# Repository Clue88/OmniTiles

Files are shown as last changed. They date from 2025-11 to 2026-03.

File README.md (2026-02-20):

# OmniTiles

OmniTiles is a robotics testing platform for ESE Senior Design (2025-26). The main controller is an
STM32F7 that drives the actuators connected to a DWM3001CDK that acts as a wireless bridge (BLE with
Nordic UART Service to STM32 over SPI). A Python GUI can be used for debugging and sending commands.

## Project Layout

**[omnitiles/](omnitiles/)** — Rust firmware for the STM32F7. Handles command parsing, motor
control, and communication over UART and SPI. This is the main firmware.

**[dwm_tag/](dwm_tag/)** — Zephyr app for the nRF52 DWM tag. Receives data over the Nordic UART
Service and passes it to the STM32 over SPI.

**[gui/](gui/)** — Python debug GUI (Viser). Web UI on localhost:8080 to send commands. Connects
over BLE to the DWM tag or optionally over serial.

## System Diagram

```
┌─────────────────┐     BLE (NUS)      ┌──────────────┐    SPI (slave)     ┌─────────────────┐
│  GUI            │ ─────────────────► │  DWM tag     │ ─────────────────► │  OmniTiles      │
│  (Python)       │                    │  (nRF52)     │   DRDY + payload   │  firmware       │
│  localhost:8080 │                    │  OmniTile_1  │                    │  (STM32F7)      │
└─────────────────┘                    └──────────────┘                    └─────────────────┘
        │                                                                          │
        │  UART (e.g. dev board or USB–UART bridge on PCB)                         │
        └──────────────────────────────────────────────────────────────────────────┘
```

Commands from host to STM32 all use the same format: sync byte `0xA5`, message ID, checksum. See
[omnitiles/src/protocol/messages.rs](omnitiles/src/protocol/messages.rs) for the IDs and
[omnitiles/src/protocol/parser.rs](omnitiles/src/protocol/parser.rs) for the parser.

## Quick Start

- **STM32 firmware:** [omnitiles/README.md](omnitiles/README.md) — Rust toolchain, flash, and how to
attach a terminal (`screen` at 115200).
- **DWM tag (nRF52):** [dwm_tag/README.md](dwm_tag/README.md) — building and flashing with the nRF
Connect extension in VS Code.
- **GUI:** [gui/README.md](gui/README.md) — run the Python app, BLE vs UART.

## Documentation

Rust API docs: from the repo root, `cd omnitiles && cargo doc --no-deps --open`. The same docs are
built in CI and published to GitHub Pages on push to `main`. Protocol message definitions and the
parser are in the `omnitiles/src/protocol/` tree.

## License

MIT. See [LICENSE](LICENSE).

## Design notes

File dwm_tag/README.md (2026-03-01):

# DWM tag: BLE-to-SPI bridge

This folder contains the Zephyr firmware for the DWM tag (nRF52) on the OmniTiles. The tag runs as a
BLE peripheral using the Nordic UART Service (NUS). Whatever it receives over BLE it forwards to the
STM32 over SPI, with the nRF52 as SPI slave. The [GUI](../gui/) (or any NUS client) can send command
packets over the air, and the [OmniTiles firmware](../omnitiles/) on the STM32 reads them via SPI.

## Building and flashing (nRF Connect for VS Code)

We use the **nRF Connect for VS Code** extension for building and flashing the DWM tag.

1. Install the [nRF Connect for VS Code](https://marketplace.visualstudio.com/items?itemName=nordic-semiconductor.nrf-connect-for-vscode)
extension if you haven’t already.
2. Open the `dwm_tag` folder in VS Code (or open the repo and have `dwm_tag` as the active folder
for the nRF extension).
3. In the nRF Connect sidebar, add the corresponding build configuration (use `prj.conf` and
`app.overlay` when prompted).
4. Use **Build** to compile the application.
5. Connect the DWM tag and use **Flash** to program it. The extension will use the configured board
and probe.

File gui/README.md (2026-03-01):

# OmniTiles GUI

Python GUI for driving the tile during development. It runs a Viser server (web UI at
http://localhost:8080) with various controls.

The GUI prefers BLE: it scans for the DWM tag and sends command packets over the Nordic UART
Service. If you pass `--port`, it also opens that serial port; when BLE isn’t connected it will send
commands over UART instead. When a serial port is open, the GUI reads lines from UART and prints
them to the console so you can see STM32 debug output.

**Requirements:** Python 3.12+. Dependencies are in [pyproject.toml](pyproject.toml).

**Run:**

```bash
uv sync
uv run python main.py
```

Optional: `--port <device>` to attach a serial port (e.g. `/dev/tty.usbmodem*`), `--baud <rate>`
(default 115200).

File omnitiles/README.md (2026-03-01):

# OmniTiles firmware

Rust firmware for the main MCU (STM32F7). It parses commands from the host over SPI (when the
[DWM tag](../dwm_tag/) is present) or over UART, and drives the actuators and debug output. For how
this fits with the DWM tag and the [GUI](../gui/), see the [root README](../README.md).

See the [generated documentation](https://clue88.github.io/OmniTiles/omnitiles/index.html) for more
details on the Rust firmware for this project.

## Installation

Written for macOS; should work on other Unix-like systems.

Install Rust if needed:

```bash
curl --proto '=https' --tlsv1.2 -sSf https://sh.rustup.rs | sh
```

Then:

```bash
rustup target add thumbv7em-none-eabihf
cargo install probe-rs-tools
```

## Usage

```bash
cargo run --release
```

To watch debug output, attach to the UART at 115200, e.g.:

```bash
screen /dev/tty.usbmodem* 115200
```

Exit screen with `Ctrl+A`, then `Ctrl+\`, then `y`. You can also use `cargo build --release` and
`cargo flash --release` separately. More on the template:
[stm32-template](https://github.com/burrbull/stm32-template/).

### USB–UART bridge (RP2040) on PCB v1

The PCB has an RP2040 (Pico) in front of the MCU UART. To get a debug serial port you need to flash
a USB–UART firmware on the RP2040 once (not needed on a bare dev board). Download the `.uf2` from
[pico-uart-bridge](https://github.com/Noltari/pico-uart-bridge/releases/tag/v4.2), hold BOOT on the
RP2040, plug USB, release BOOT, then drag the `.uf2` onto the `RPI-RP2` volume. After that the debug
terminal works as above.

## Documentation

Message IDs and the frame parser live in `src/protocol/` ([messages.rs](src/protocol/messages.rs),
[parser.rs](src/protocol/parser.rs)).

```bash
cargo doc --no-deps --open
```

CI builds these docs and deploys them to GitHub Pages on push to `main`.

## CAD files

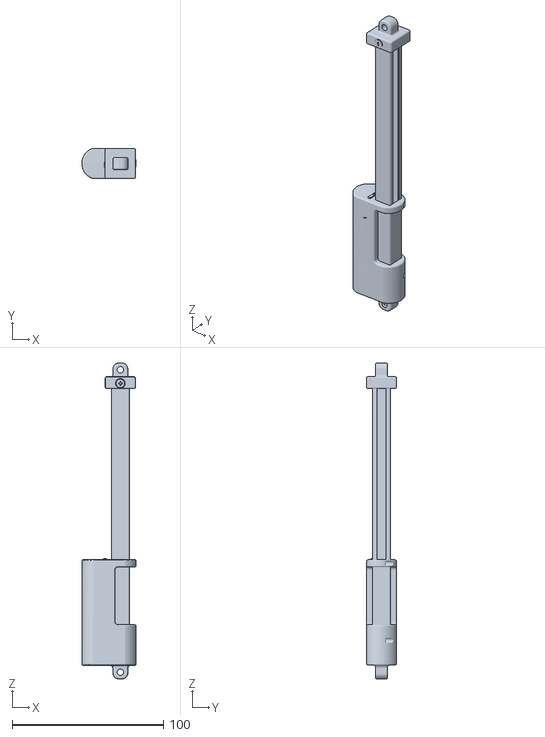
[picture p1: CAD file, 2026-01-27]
gui/t16_base.stl
36.0 x 20.0 x 208.9

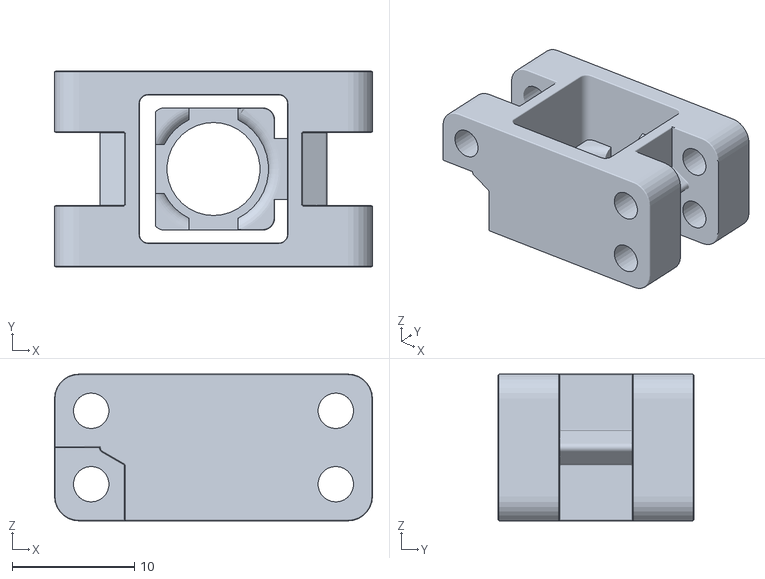
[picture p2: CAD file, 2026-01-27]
gui/t16_carriage.stl
26.0 x 16.0 x 12.0

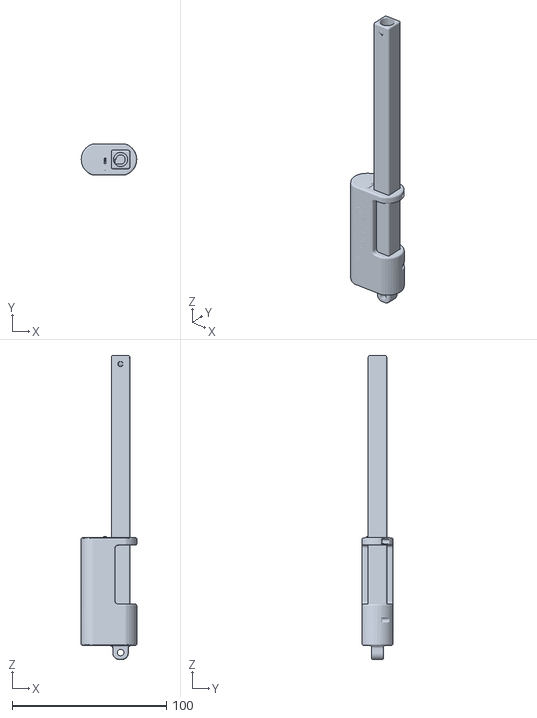
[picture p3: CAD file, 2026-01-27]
gui/p16_base.stl
36.0 x 20.0 x 196.9

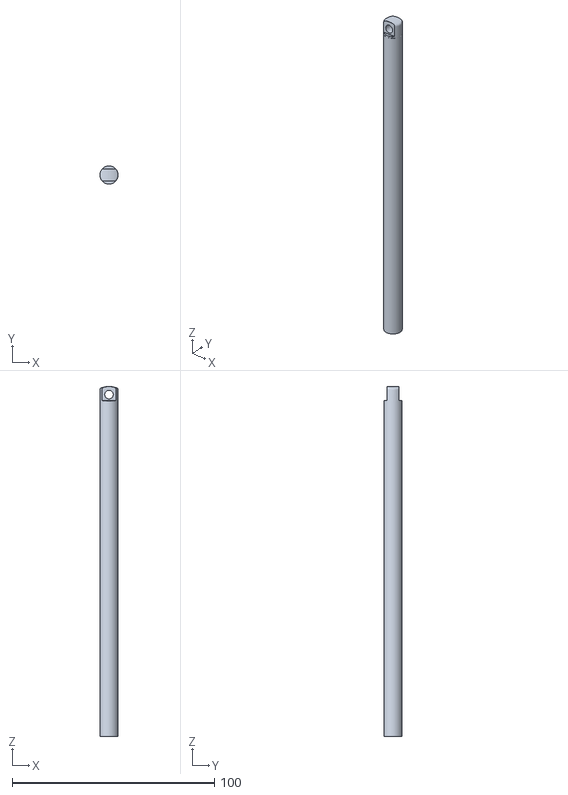
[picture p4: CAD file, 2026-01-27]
gui/p16_shaft.stl
9.00 x 9.00 x 173.0

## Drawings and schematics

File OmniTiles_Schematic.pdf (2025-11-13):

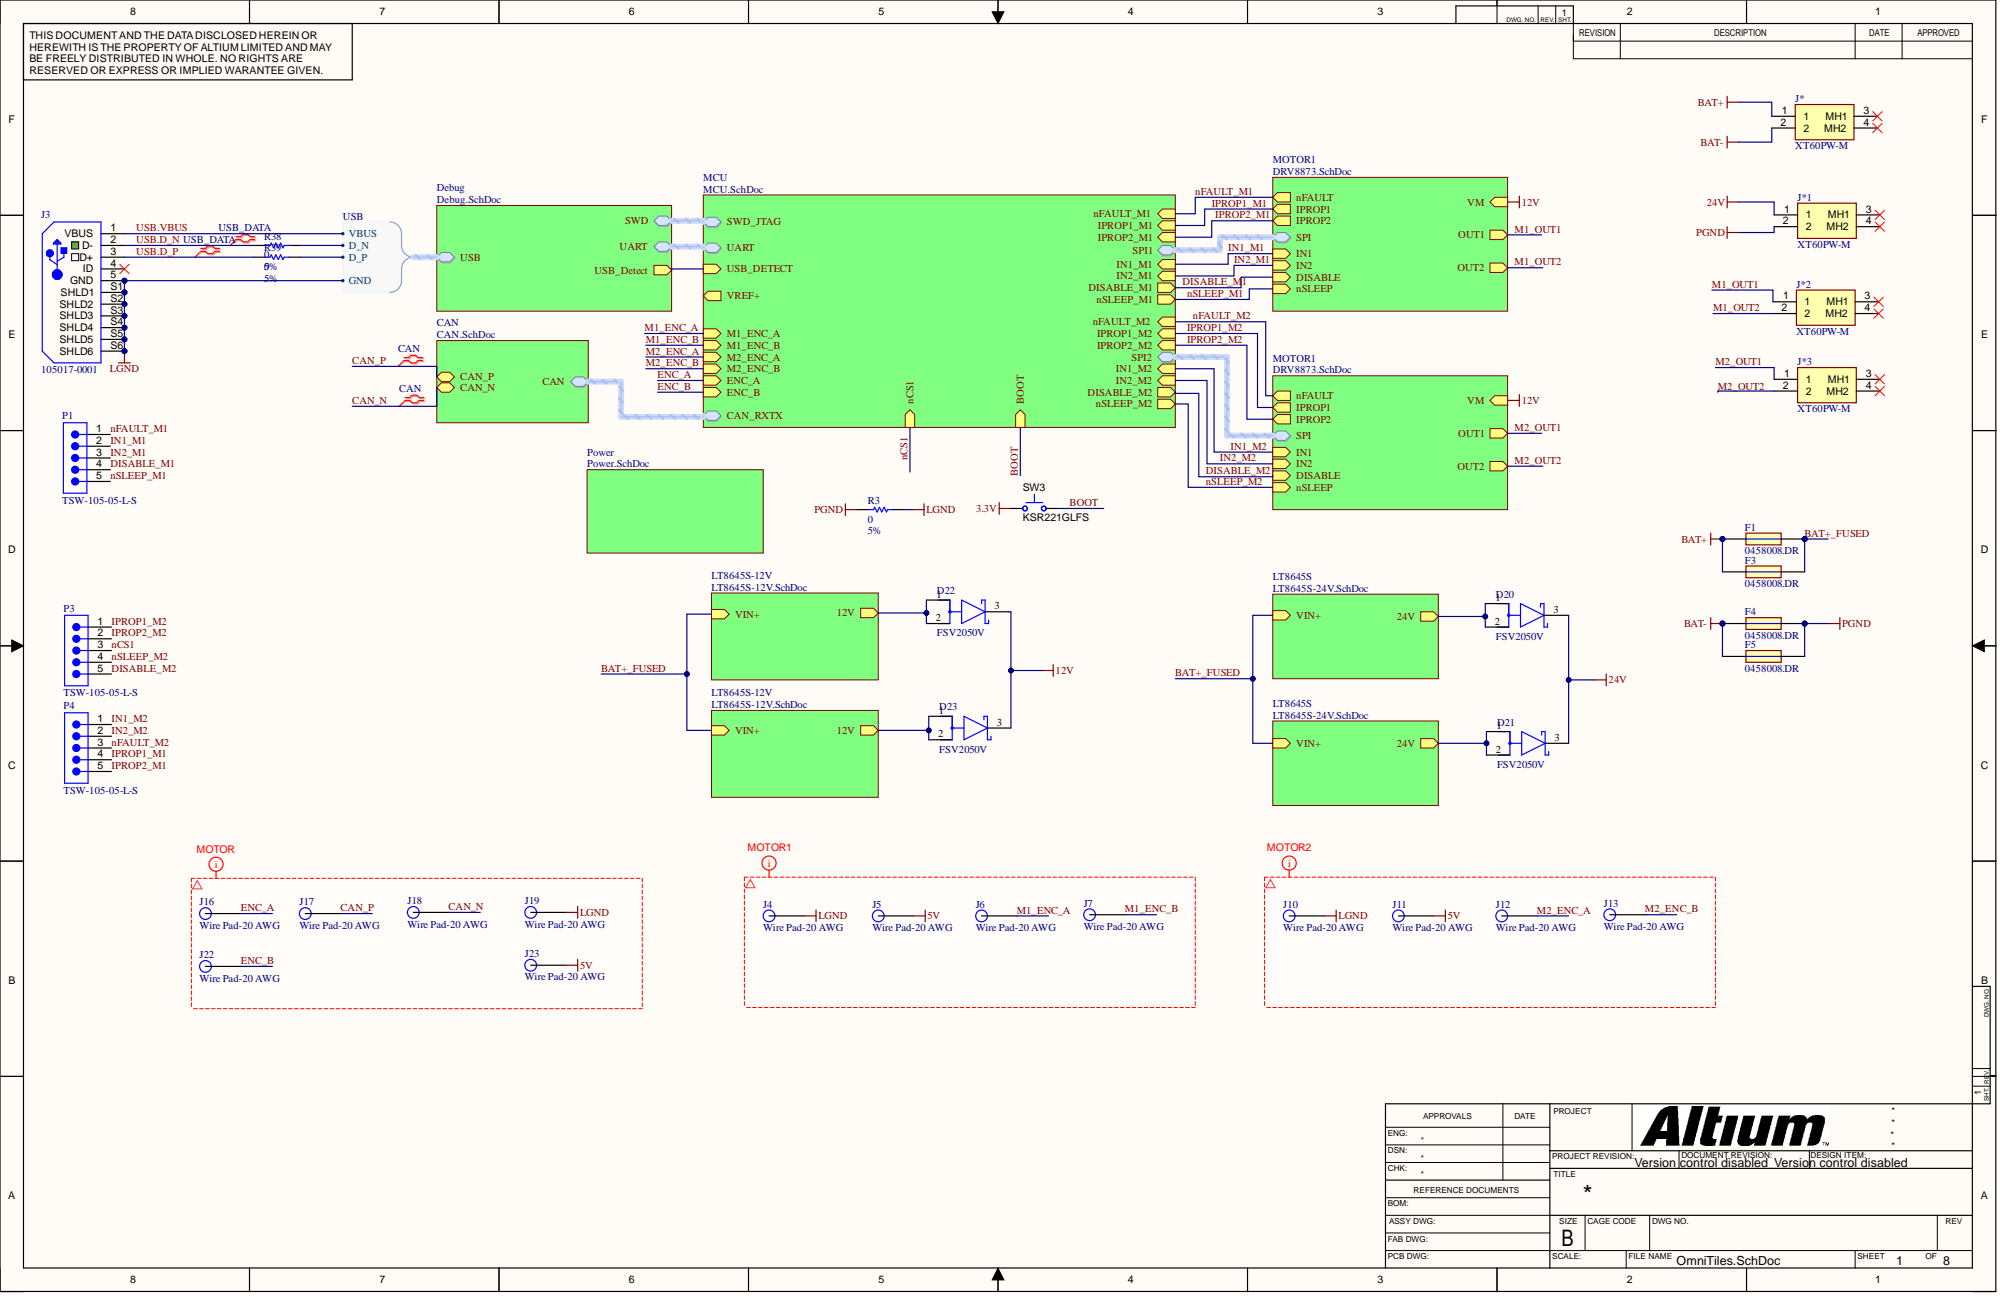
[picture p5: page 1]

DWG. NO. | REV. | SHT.

THIS DOCUMENT AND THE DATA DISCLOSED HEREIN OR HEREWITH IS THE PROPERTY OF ALTIUM LIMITED AND MAY BE FREELY DISTRIBUTED IN WHOLE. NO RIGHTS ARE RESERVED OR EXPRESS OR IMPLIED WARANTEE GIVEN. | MOTOR1 DRV8873.SchDoc | REVISION | DESCRIPTION | DATE | APPROVED

IN2_M2
DISABLE_M2

REV. SHT. DWG. NO.

DATE | PROJECT | * * APPROVALS * *

ENG: *

DSN: *

PROJECT REVISION: Version | DOCUMENT REVISION: control disabled Version control disabled | DESIGN ITEM:

CHK: *

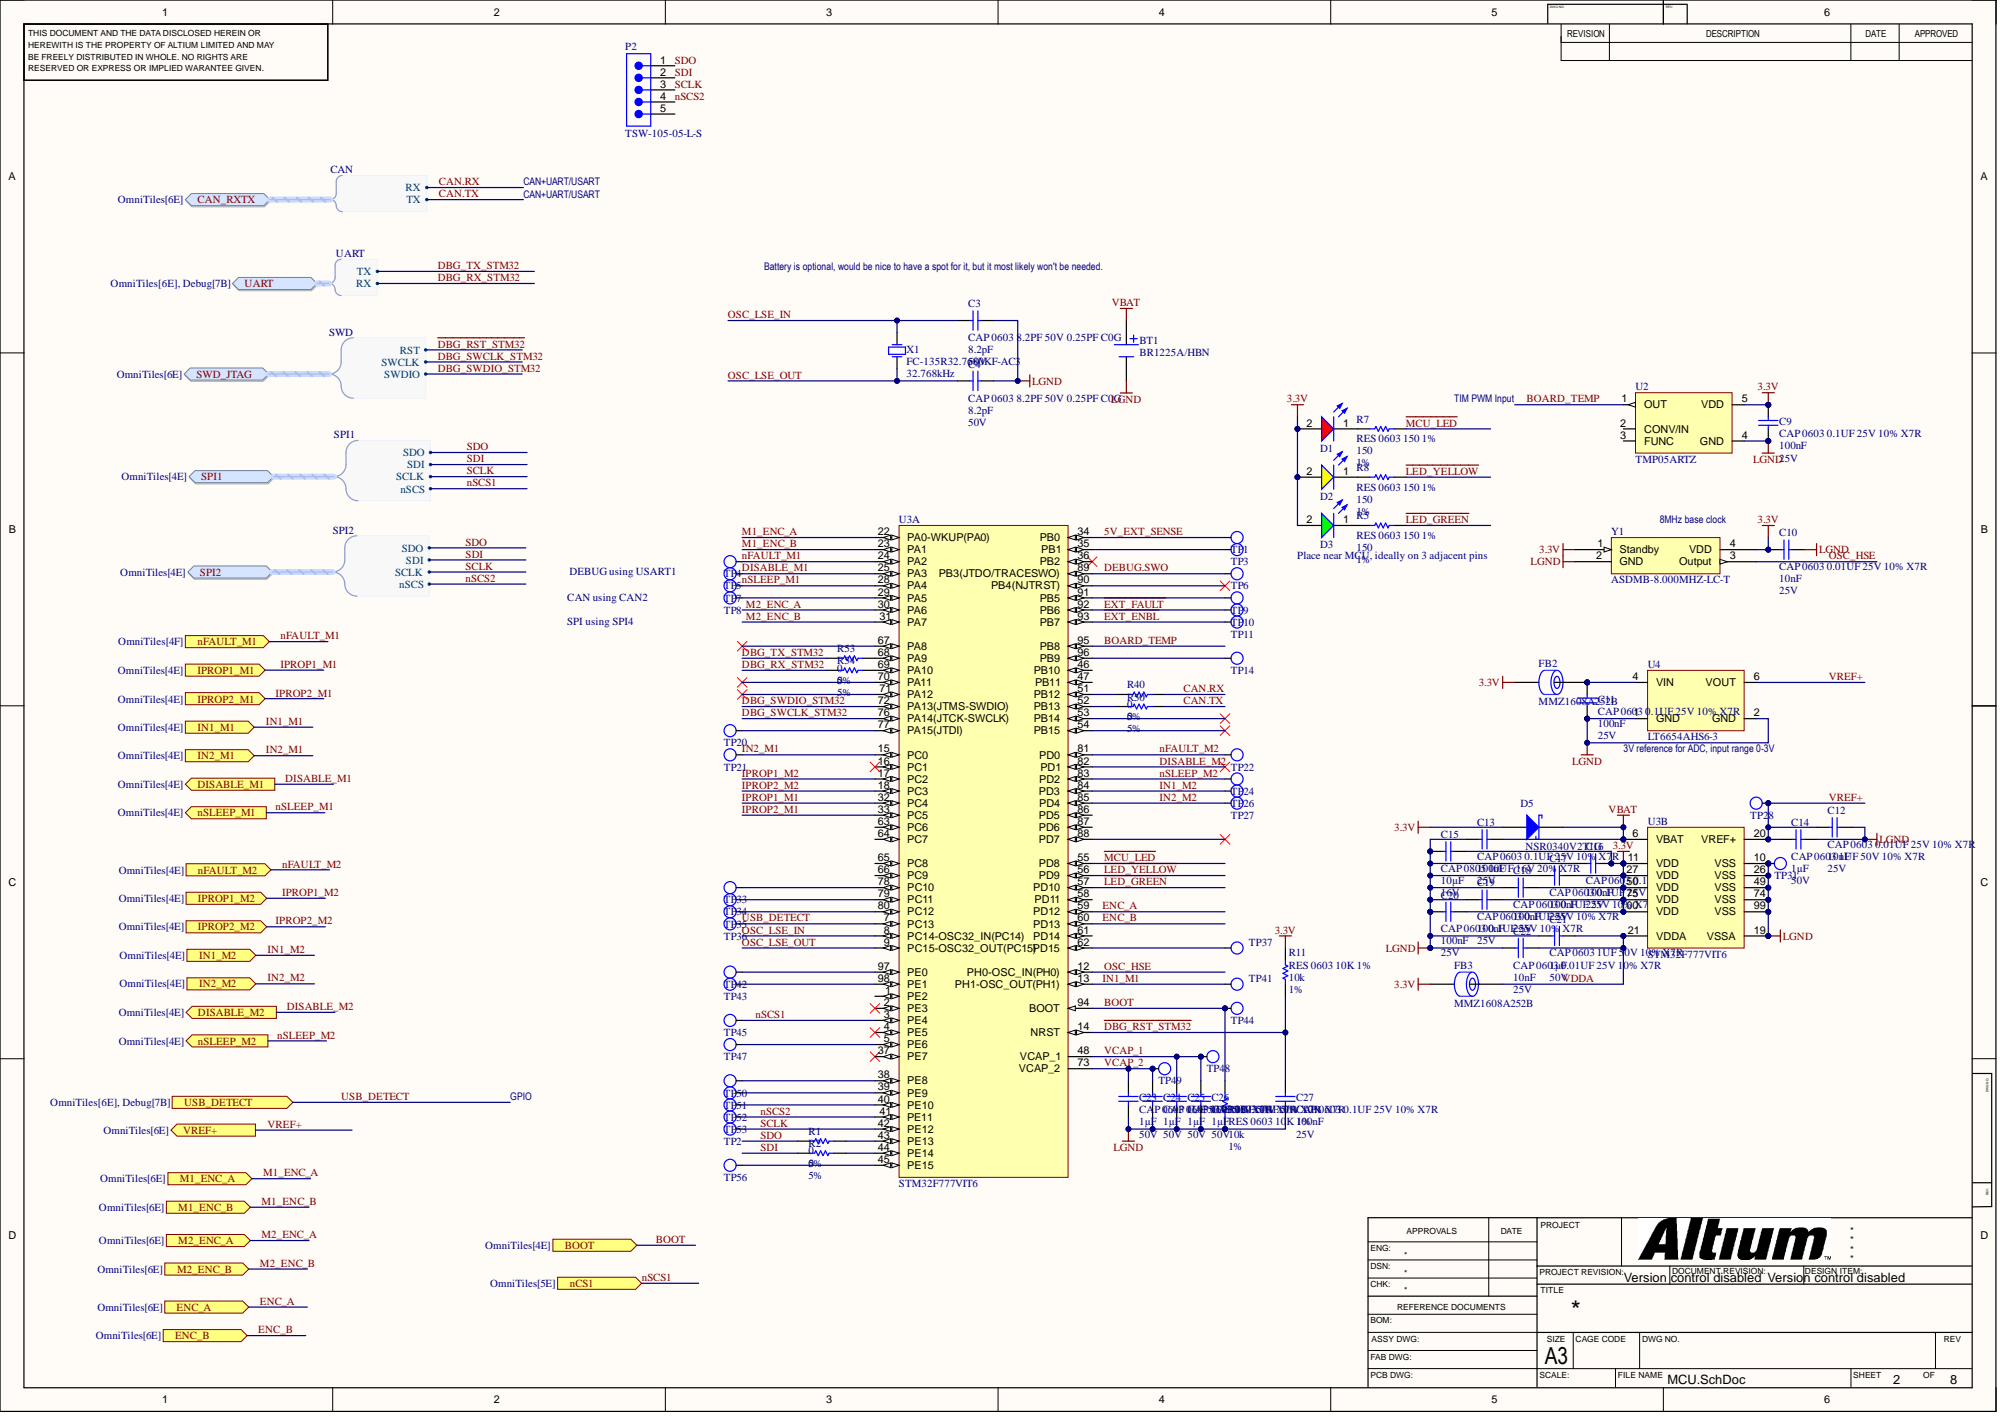
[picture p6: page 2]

DWG NO: | REV:

THIS DOCUMENT AND THE DATA DISCLOSED HEREIN OR HEREWITH IS THE PROPERTY OF ALTIUM LIMITED AND MAY BE FREELY DISTRIBUTED IN WHOLE. NO RIGHTS ARE RESERVED OR EXPRESS OR IMPLIED WARANTEE GIVEN. | P2 | REVISION | DESCRIPTION | DATE | APPROVED

Battery is optional, would be nice to have a spot for it, but it most likely won't be needed.

Place near MCU, ideally on 3 adjacent pins

DBG_RST_STM32

VCAP_1
VCAP_2

DATE | PROJECT | * * APPROVALS * *

ENG: *

DSN: *

CHK: *

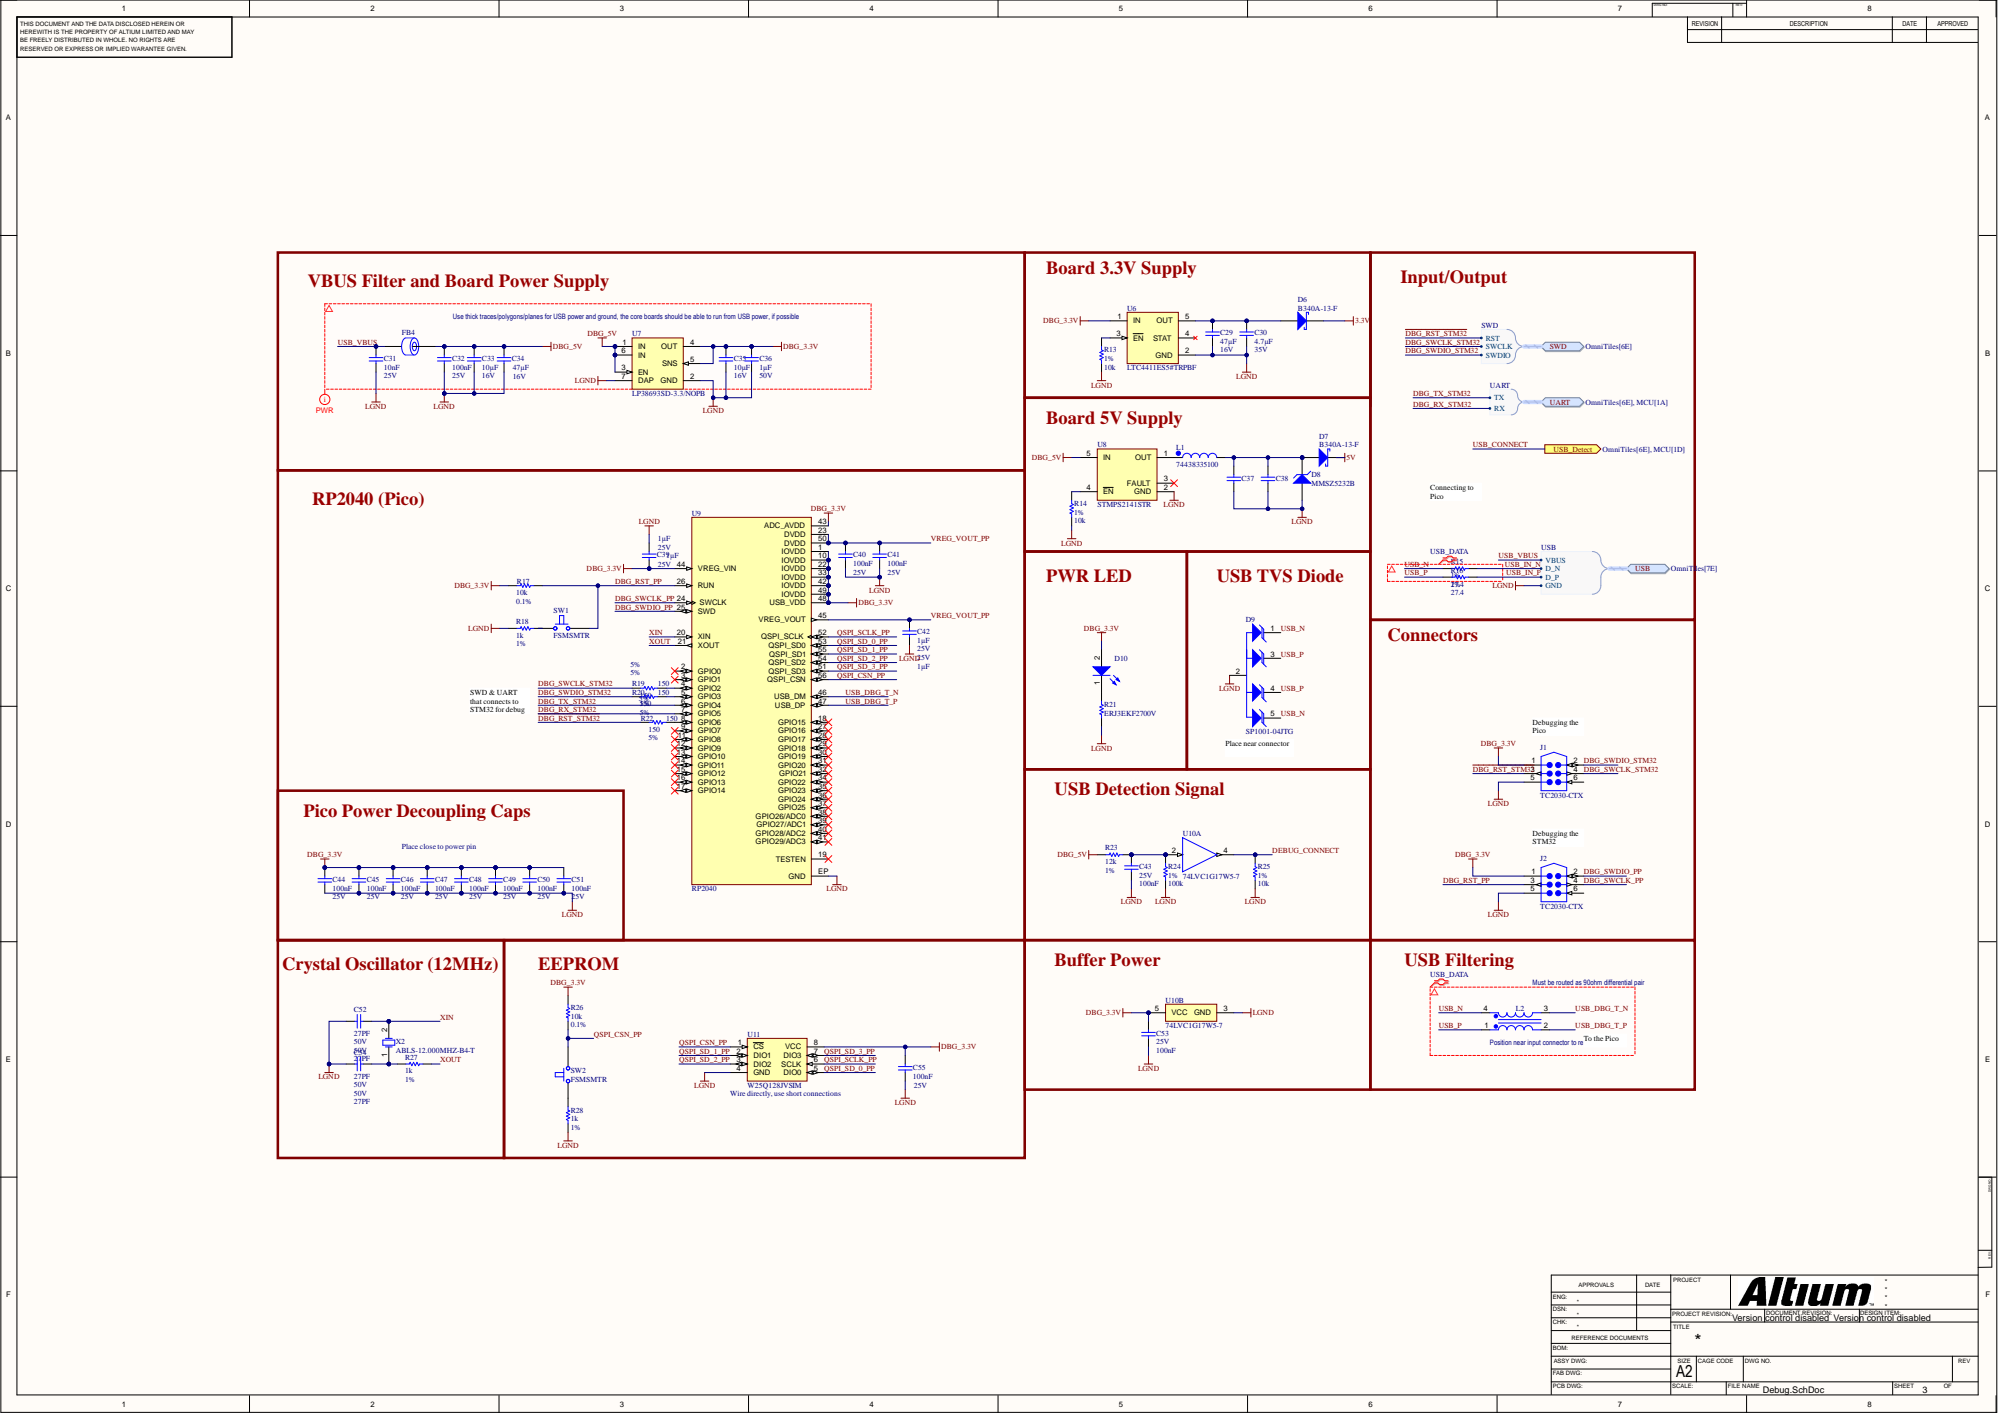
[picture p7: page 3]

DWG NO: | REV:

THIS DOCUMENT AND THE DATA DISCLOSED HEREIN OR HEREWITH IS THE PROPERTY OF ALTIUM LIMITED AND MAY BE FREELY DISTRIBUTED IN WHOLE. NO RIGHTS ARE RESERVED OR EXPRESS OR IMPLIED WARANTEE GIVEN. | | REVISION | DESCRIPTION | DATE | APPROVED

Use thick traces/polygons/planes for USB power and ground, the core boards should be able to run from USB power, if possible

Pico Power Decoupling Caps

Place close to power pin

Must be routed as 90ohm differential pair

Position near input connector to remove HF noise

W25Q128JVSIM
Wire directly, use short connections

DATE | PROJECT | * * APPROVALS * *

ENG: *

DSN: *

PROJECT REVISION: Version | DOCUMENT REVISION: control disabled Version control disabled | DESIGN ITEM:

CHK: *

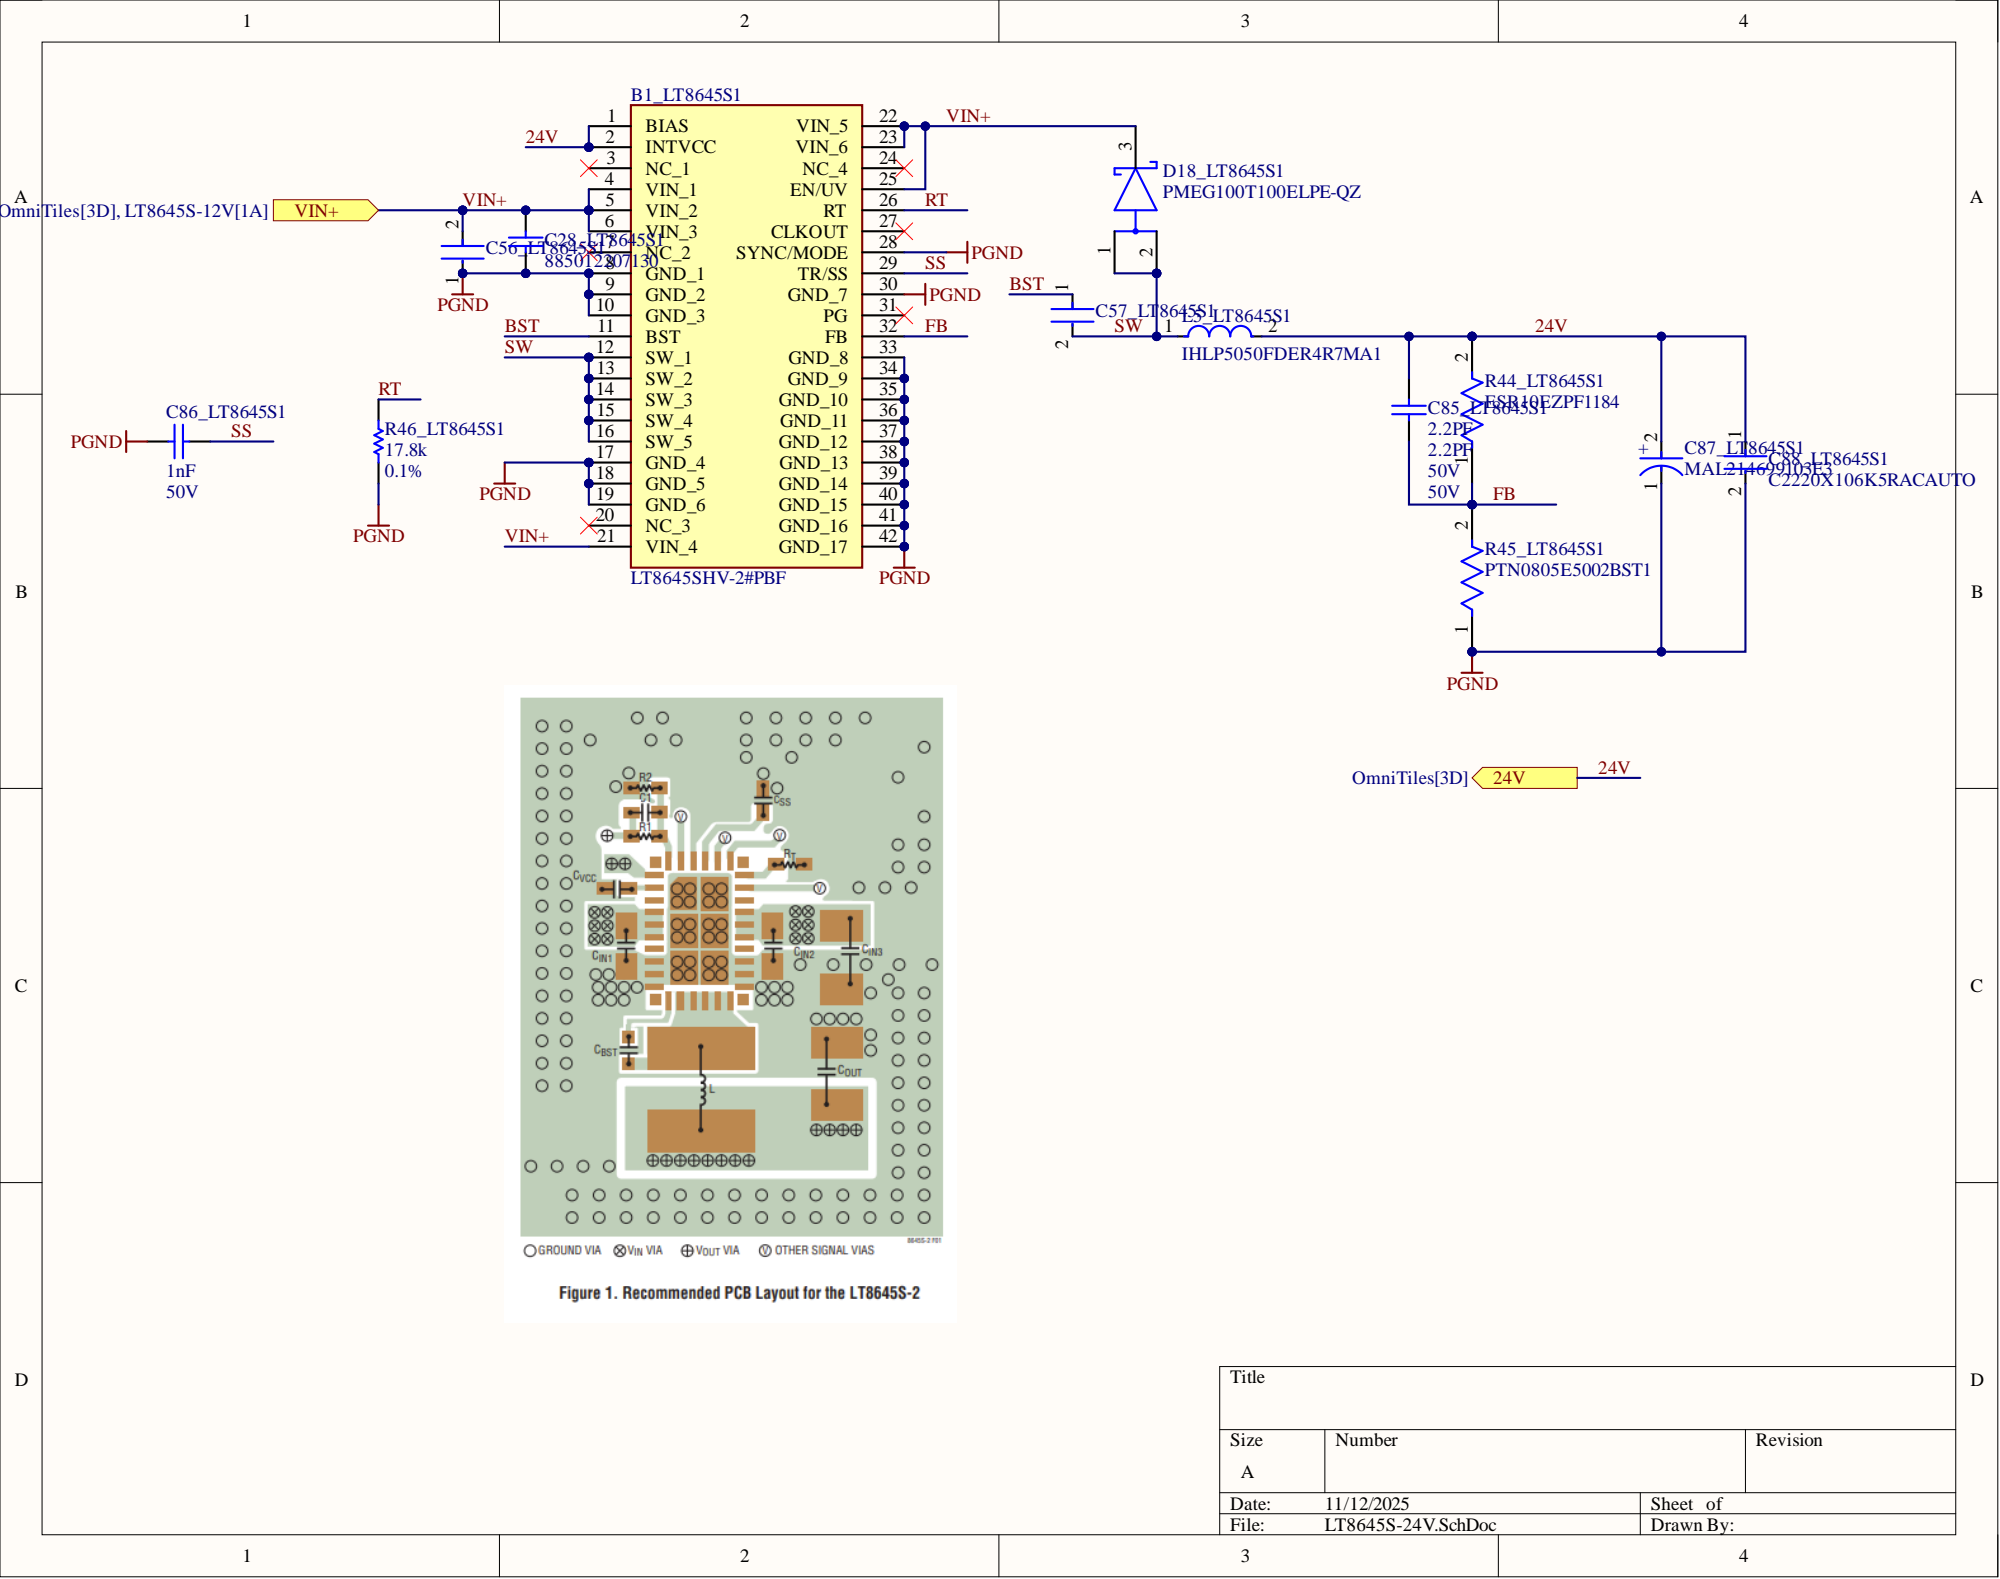
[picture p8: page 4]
PIC280LT8645S102 COC28; PIC560LT8645S102 COC56; PIC570LT8645S102 COC57; PIC850LT8645S102 COC85; PIC870LT8645S102 COC87; PIC880LT8645S101; PIC880LT8645S102 COC88; PID180LT8645S101 PID180LT8645S102; PID180LT8645S103 COD18; PIR440LT8645S102 COR44; PIR450LT8645S102 COR45; PIR460LT8645S102 COR46; PIR460LT8645S102 NLRT; NLVIN0 POVIN0; PIC280LT8645S202 COC28; PIC560LT8645S202 COC56; PIC570LT8645S202 COC57; PIC850LT8645S202 COC85; PIC870LT8645S202 COC87; PIC880LT8645S201; PIC880LT8645S202 COC88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

2 PIB10LT8645S102 PIB10LT8645S102 PIB10LT8645S202 PIB10LT8645S202 | 2 3 PIB10LT8645S1023 PIB10LT8645S1023 PIB10LT8645S2023 PIB10LT8645S2023

2 4 PIB10LT8645S1024 PIB10LT8645S1024 PIB10LT8645S2024 PIB10LT8645S2024

N D | 9 PIB10LT8645S109 PIB10LT8645S109 PIB10LT8645S209 PIB10LT8645S209

1 0 PIB10LT8645S1010 PIB10LT8645S1010 PIB10LT8645S2010 PIB10LT8645S2010 | | PIB10LT8645S1031 PIB10LT8645S1031 PIB10LT8645S2031 PIB10LT8645S2031

1 5 PIB10LT8645S1015 PIB10LT8645S1015 PIB10LT8645S2015 PIB10LT8645S2015 | 3 6
1 6 PIB10LT8645S1016 PIB10LT8645S1016 PIB10LT8645S2016 PIB10LT8645S2016 | 3 7 PIB10LT8645S1037 PIB10LT8645S1037 PIB10LT8645S2037 PIB10LT8645S2037

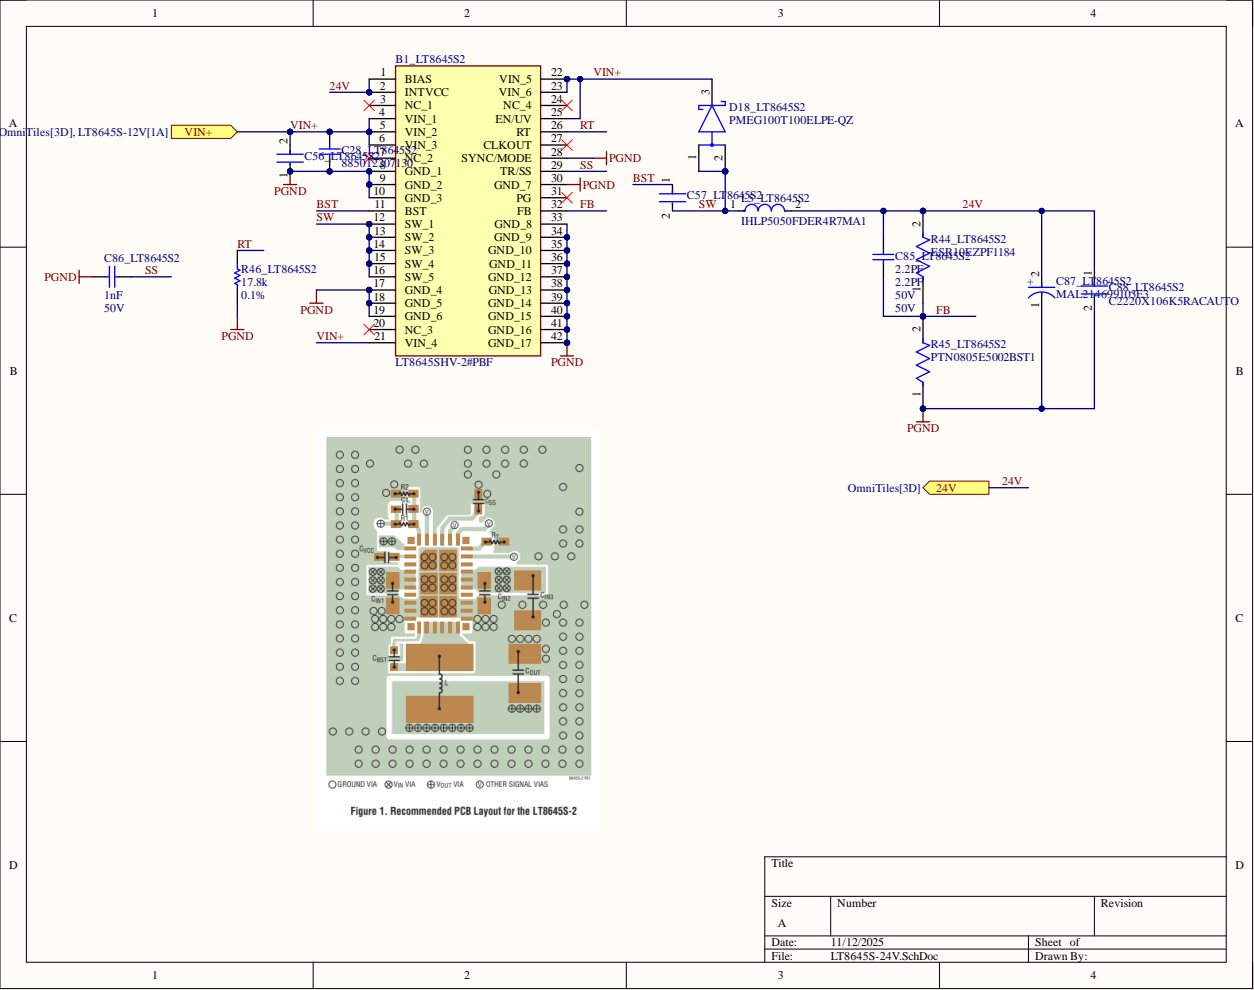
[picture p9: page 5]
Date:; Sheet of; File:; LT8645S-24V.SchDoc; Drawn By:; BIAS 1 INTVCC 2 NC_1 3 VIN_1 4 VIN_2 5 VIN_3 6 NC_2 7 GND_1 8 GND_2 9 GND_3 10 BST 11 SW_1 12 SW_2 13 SW_3 14 SW_4 15 SW_5 16 GND_4 17 GND_5 18 GND_6 19 NC_3 20 VIN_4 21; 2 D18_LT8645S2 PMEG100T100ELPE-QZ VIN+; OmniTiles[3D], LT8645S-12V[1A]; VIN+

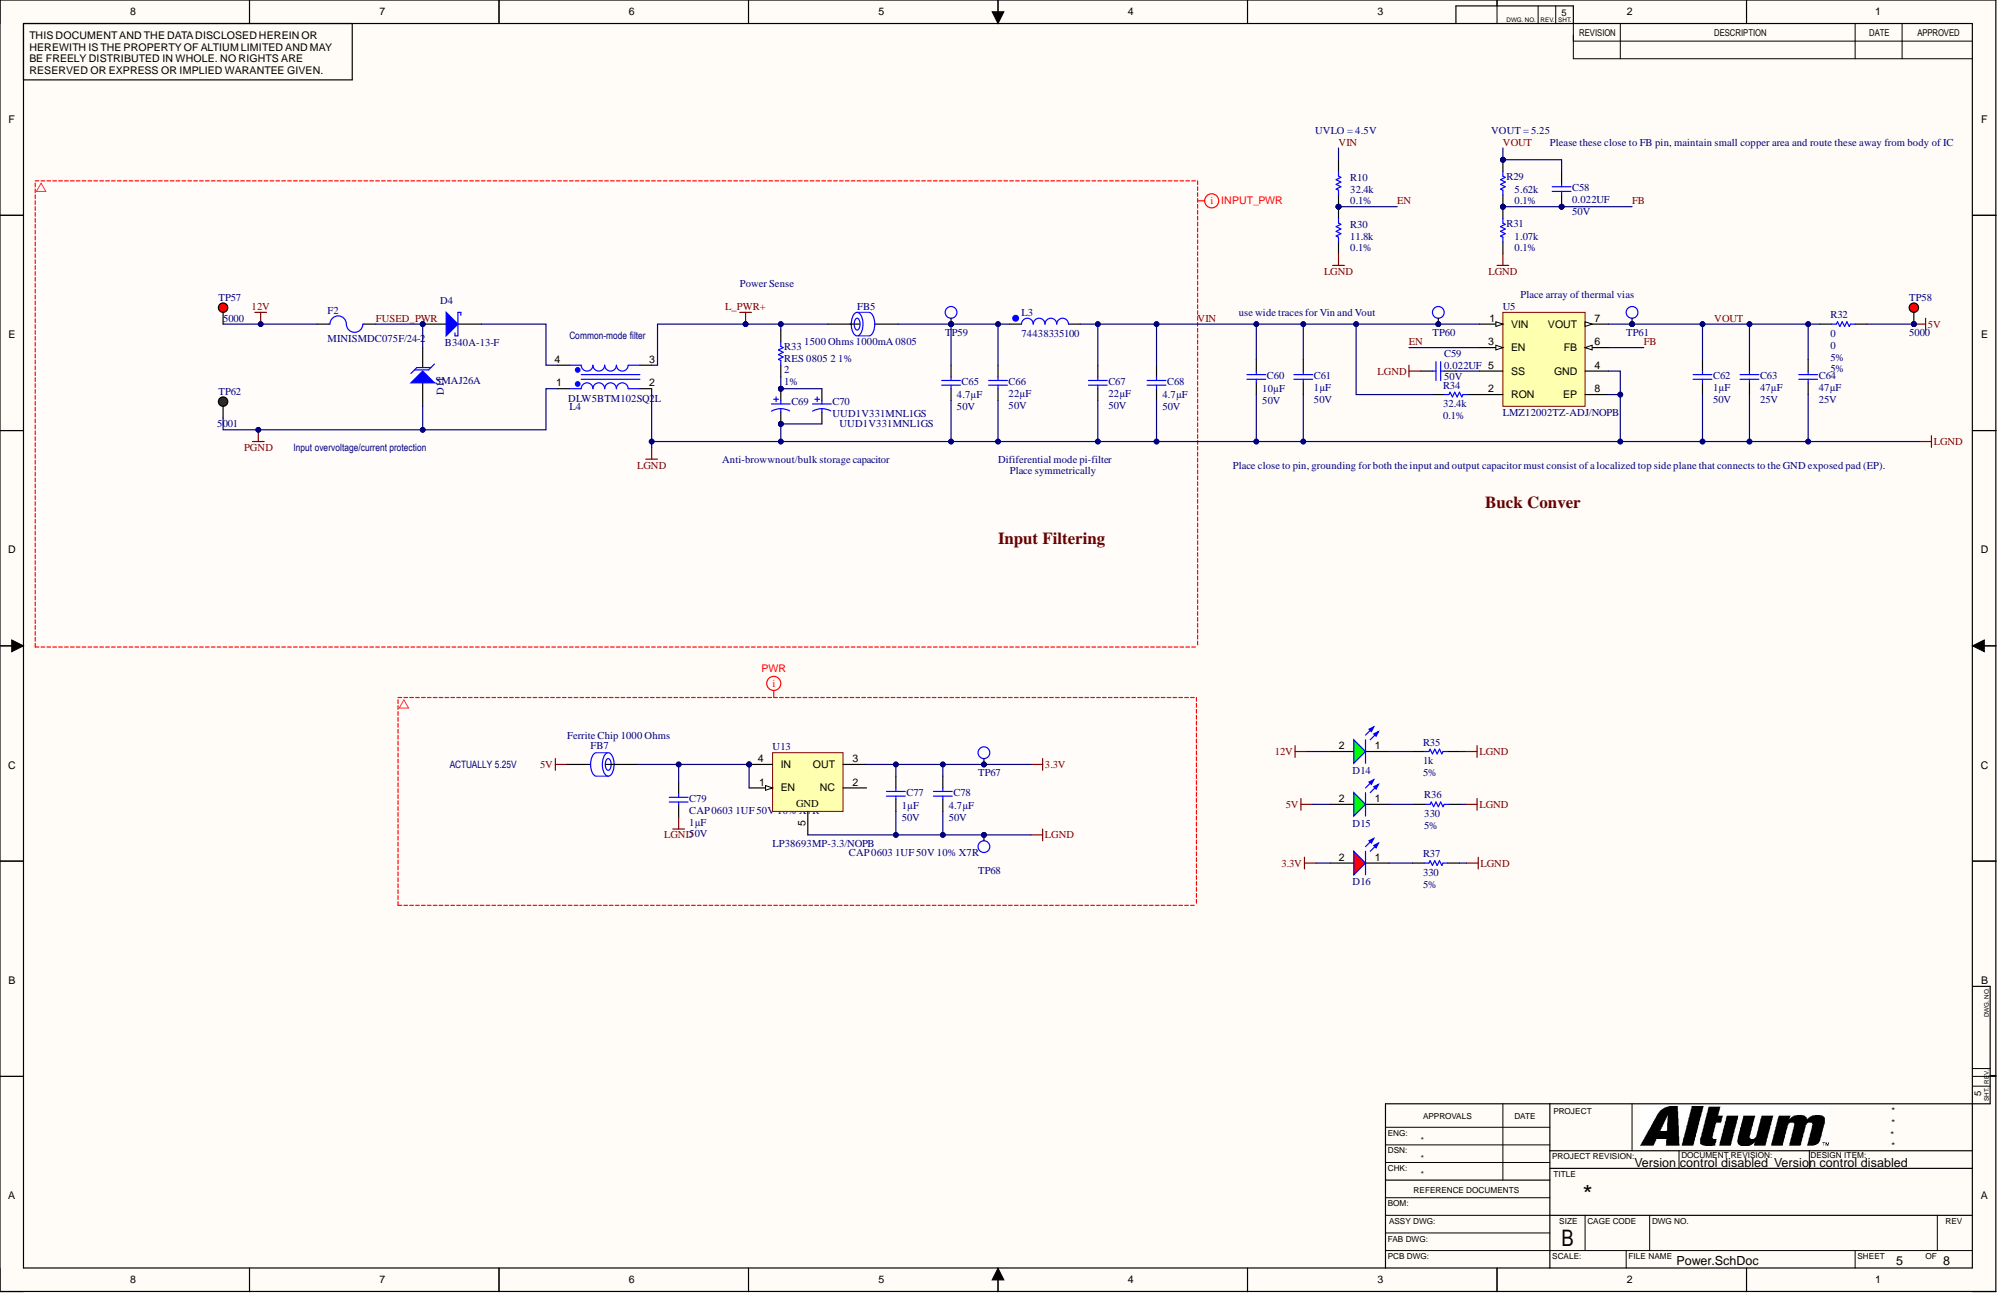
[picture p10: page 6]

DWG. NO. | REV. | SHT.

THIS DOCUMENT AND THE DATA DISCLOSED HEREIN OR HEREWITH IS THE PROPERTY OF ALTIUM LIMITED AND MAY BE FREELY DISTRIBUTED IN WHOLE. NO RIGHTS ARE RESERVED OR EXPRESS OR IMPLIED WARANTEE GIVEN. | UVLO = 4.5V VOUT = 5.25 VIN VOUT | REVISION | DESCRIPTION | DATE | APPROVED

Please these close to FB pin, maintain small copper area and route these away from body of IC

Place array of thermal vias
5V TP61 VIN 1

use wide tracesfor Vin and Vout 12V

Input overvoltage/current protection

Anti-browwnout/bulk storage capacitor

Dififerential mode pi-filter
Place symmetrically

Place close to pin, grounding for both the input and output capacitor must consist of a localized top side plane that connects to the GND exposed pad (EP).

REV. SHT. DWG. NO.

DATE | PROJECT | * * APPROVALS * *

ENG: *

DSN: *

PROJECT REVISION: Version | DOCUMENT REVISION: control disabled Version control disabled | DESIGN ITEM:

CHK: *
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

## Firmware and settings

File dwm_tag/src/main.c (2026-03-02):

// SPDX-License-Identifier: MIT
// © 2025–2026 Christopher Liu

/*
 * DWM tag (nRF52) application: BLE-to-SPI bridge.
 *
 * Runs as a BLE peripheral (Nordic UART Service), advertising as OmniTile_1.
 * Data received from a device is queued and then sent to the STM32 over SPI when
 * the master asserts CS. A DRDY GPIO is driven high when a payload is ready and
 * cleared after the SPI transaction completes.
 */

#include <bluetooth/services/nus.h>
#include <zephyr/bluetooth/bluetooth.h>
#include <zephyr/bluetooth/conn.h>
#include <zephyr/bluetooth/gatt.h>
#include <zephyr/bluetooth/uuid.h>
#include <zephyr/drivers/gpio.h>
#include <zephyr/drivers/spi.h>
#include <zephyr/kernel.h>
#include <zephyr/logging/log.h>
#include <zephyr/net/ieee802154_mgmt.h>
#include <zephyr/net/net_if.h>
#include <zephyr/net/net_ip.h>
#include <zephyr/net/net_mgmt.h>
#include <zephyr/net/socket.h>

LOG_MODULE_REGISTER(main);

#define UWB_THREAD_STACK_SIZE 2048
#define UWB_THREAD_PRIORITY   10
#define UWB_POLL_INTERVAL_MS  100
#define UWB_ANCHOR_PORT       4242
#define UWB_POLL_PAYLOAD      "Poll"
#define UWB_POLL_LEN          4

#define SPI_SLAVE_NODE DT_NODELABEL(my_spis)
#define DRDY_GPIO_NODE DT_ALIAS(spis_drdy_gpios)
#define SPI_BUF_SIZE   128

/* Protocol: same as STM32/omnitiles (START_BYTE, msg_id, checksum). No payload => checksum = msg_id */
#define CMD_START_BYTE 0xA5
#define CMD_M1_BRAKE   0x32
#define CMD_M2_BRAKE   0x42

/* Define NUS UUID so scanners can see us in Scan Response */
#define NUS_UUID_Service_Val                                                             \
  0x9E, 0xCA, 0xDC, 0x24, 0x0E, 0xE5, 0xA9, 0xE0, 0x93, 0xF3, 0xA3, 0xB5, 0x01, 0x00,    \
      0x40, 0x6E

/* Shared state: distances to three UWB anchors in mm (volatile ok for mock) */
static volatile uint16_t uwb_distances_mm[3] = {0, 0, 0};

static const struct bt_data ad[] = {
    BT_DATA_BYTES(BT_DATA_FLAGS, (BT_LE_AD_GENERAL | BT_LE_AD_NO_BREDR)),
    BT_DATA(BT_DATA_NAME_COMPLETE, "OmniTile_1", 10),
};

static const struct bt_data sd[] = {
    BT_DATA_BYTES(BT_DATA_UUID128_ALL, NUS_UUID_Service_Val),
};

static struct k_work adv_work;
static struct bt_conn* current_conn;

/* Avoid flooding BLE and stressing stack: rate-limit NUS send and back off on failure */
#define NUS_SEND_INTERVAL_MS 50
#define NUS_SEND_BACKOFF_MS  3000
static uint32_t last_nus_send_ms;
static uint32_t nus_send_backoff_until_ms;

/* Set in disconnected(); main loop sends M1+M2 brake to STM32 on next SPI transaction */
static volatile bool send_brake_on_disconnect;
/* Set in bt_receive_cb when queue is full; main loop sends M1+M2 brake on next SPI transaction */
static volatile bool send_brake_on_queue_full;

static void adv_work_handler(struct k_work* work) {
  int err =
      bt_le_adv_start(BT_LE_ADV_CONN_FAST_1, ad, ARRAY_SIZE(ad), sd, ARRAY_SIZE(sd));
  if (err) {
    LOG_ERR("Advertising failed to restart (err %d)", err);
  }
}

static const struct device* const spi_dev = DEVICE_DT_GET(SPI_SLAVE_NODE);
static const struct gpio_dt_spec drdy_pin = GPIO_DT_SPEC_GET(DRDY_GPIO_NODE, gpios);

K_MSGQ_DEFINE(ble_msgq, SPI_BUF_SIZE, 32, 4);

static uint8_t tx_buffer[SPI_BUF_SIZE];
static uint8_t rx_buffer[SPI_BUF_SIZE];

static const struct spi_config spi_cfg = {
    .operation = SPI_WORD_SET(8) | SPI_TRANSFER_MSB | SPI_OP_MODE_SLAVE,
};

static void set_drdy(bool active) {
  gpio_pin_set_dt(&drdy_pin, active ? 1 : 0);
}

/* BLE callbacks */

static void bt_receive_cb(struct bt_conn* conn, const uint8_t* const data, uint16_t len) {
  uint8_t temp_buf[SPI_BUF_SIZE];

  uint16_t copy_len = (len > SPI_BUF_SIZE) ? SPI_BUF_SIZE : len;
  memcpy(temp_buf, data, copy_len);

  if (copy_len < SPI_BUF_SIZE) {
    memset(temp_buf + copy_len, 0, SPI_BUF_SIZE - copy_len);
  }

  if (k_msgq_put(&ble_msgq, temp_buf, K_NO_WAIT) != 0) {
    LOG_WRN("BLE Queue Full");
    send_brake_on_queue_full = true;
  }
}

static struct bt_nus_cb nus_cb = {
    .received = bt_receive_cb,
};

static void connected(struct bt_conn* conn, uint8_t err) {
  if (err) {
    LOG_ERR("Connection failed (err 0x%02x)", err);
    return;
  }

  LOG_INF("Connected");

  /* Track the current connection for NUS TX */
  current_conn = bt_conn_ref(conn);
}

static void disconnected(struct bt_conn* conn, uint8_t reason) {
  LOG_INF("Disconnected (reason 0x%02x). Restarting advertising...", reason);

  if (current_conn == conn) {
    send_brake_on_disconnect = true;
    bt_conn_unref(current_conn);
    current_conn = NULL;
    nus_send_backoff_until_ms = 0;
  }

  k_work_submit(&adv_work);
}

BT_CONN_CB_DEFINE(conn_callbacks) = {
    .connected = connected,
    .disconnected = disconnected,
};

static void bt_ready(int err) {
  if (err) {
    LOG_ERR("BLE init failed (err %d)", err);
    return;
  }
  LOG_INF("BLE Initialized");

  err = bt_nus_init(&nus_cb);
  if (err) {
    LOG_ERR("Failed to init NUS (err %d)", err);
    return;
  }

  err = bt_le_adv_start(BT_LE_ADV_CONN_FAST_1, ad, ARRAY_SIZE(ad), sd, ARRAY_SIZE(sd));
  if (err) {
    LOG_ERR("Advertising failed (err %d)", err);
  } else {
    LOG_INF("Advertising started as OmniTile_1");
  }
}

static struct net_if* uwb_iface_found;

static void find_ieee802154_cb(struct net_if* iface, void* user_data) {
  uint16_t ch;
  if (uwb_iface_found != NULL) {
    return;
  }
  if (net_mgmt(NET_REQUEST_IEEE802154_GET_CHANNEL, iface, &ch, sizeof(ch)) == 0) {
    uwb_iface_found = iface;
  }
}

static void uwb_thread_entry(void* p1, void* p2, void* p3) {
  ARG_UNUSED(p1);
  ARG_UNUSED(p2);
  ARG_UNUSED(p3);

  struct sockaddr_in6 dst;
  int fd;
  int ret;

  uwb_iface_found = NULL;
  net_if_foreach(find_ieee802154_cb, NULL);
  if (uwb_iface_found == NULL || !net_if_is_up(uwb_iface_found)) {
    LOG_ERR("UWB: no IEEE 802.15.4 interface or not up");
    k_thread_suspend(k_current_get());
    return;
  }

  fd = zsock_socket(AF_INET6, SOCK_DGRAM, IPPROTO_UDP);
  if (fd < 0) {
    LOG_ERR("UWB: socket create failed (%d)", fd);
    k_thread_suspend(k_current_get());
    return;
  }

  memset(&dst, 0, sizeof(dst));
  dst.sin6_family = AF_INET6;
  dst.sin6_port = htons(UWB_ANCHOR_PORT);
  /* ff02::1 (all-nodes multicast) */
  dst.sin6_addr.s6_addr[0] = 0xff;
  dst.sin6_addr.s6_addr[1] = 0x02;
  dst.sin6_addr.s6_addr[15] = 0x01;

  for (;;) {
    ret = zsock_sendto(
        fd, UWB_POLL_PAYLOAD, UWB_POLL_LEN, 0, (struct sockaddr*)&dst, sizeof(dst));
    if (ret < 0) {
      LOG_WRN("UWB: sendto failed (%d)", ret);
    }

    /* Mock: update distances (base + small increment to simulate movement) */
    static uint16_t tick;
    tick++;
    uwb_distances_mm[0] = 1000 + (tick % 200);
    uwb_distances_mm[1] = 2000 + (tick % 200);
    uwb_distances_mm[2] = 3000 + (tick % 200);

    k_msleep(UWB_POLL_INTERVAL_MS);
  }
}

K_THREAD_DEFINE(uwb_thread,
    UWB_THREAD_STACK_SIZE,
    uwb_thread_entry,
    NULL,
    NULL,
    NULL,
    UWB_THREAD_PRIORITY,
    0,
    0);

int main(void) {
  int ret;

  if (!gpio_is_ready_dt(&drdy_pin) || !device_is_ready(spi_dev)) {
    LOG_ERR("Hardware init failed");
    return -1;
  }
  gpio_pin_configure_dt(&drdy_pin, GPIO_OUTPUT_INACTIVE);

  k_work_init(&adv_work, adv_work_handler);

  ret = bt_enable(bt_ready);
  if (ret) {
    LOG_ERR("Bluetooth enable failed");
    return -1;
  }

  LOG_INF("System Ready. Waiting for BLE data...");

  while (1) {
    ret = k_msgq_get(&ble_msgq, tx_buffer, K_MSEC(1000));

    if (ret != 0) {
      memset(tx_buffer, 0, SPI_BUF_SIZE);
    }

    /* On BLE disconnect, send brake to STM32 so motors stop when link is lost */
    if (send_brake_on_disconnect) {
      send_brake_on_disconnect = false;
      tx_buffer[0] = CMD_START_BYTE;
      tx_buffer[1] = CMD_M1_BRAKE;
      tx_buffer[2] = CMD_M1_BRAKE;
      tx_buffer[3] = CMD_START_BYTE;
      tx_buffer[4] = CMD_M2_BRAKE;
      tx_buffer[5] = CMD_M2_BRAKE;
      memset(tx_buffer + 6, 0, SPI_BUF_SIZE - 6);
    }
    /* When queue overflowed, send brake so actuators stop immediately */
    if (send_brake_on_queue_full) {
      send_brake_on_queue_full = false;
      tx_buffer[0] = CMD_START_BYTE;
      tx_buffer[1] = CMD_M1_BRAKE;
      tx_buffer[2] = CMD_M1_BRAKE;
      tx_buffer[3] = CMD_START_BYTE;
      tx_buffer[4] = CMD_M2_BRAKE;
      tx_buffer[5] = CMD_M2_BRAKE;
      memset(tx_buffer + 6, 0, SPI_BUF_SIZE - 6);
    }

    struct spi_buf tx_buf = {.buf = tx_buffer, .len = SPI_BUF_SIZE};
    struct spi_buf_set tx = {.buffers = &tx_buf, .count = 1};

    struct spi_buf rx_buf = {.buf = rx_buffer, .len = SPI_BUF_SIZE};
    struct spi_buf_set rx = {.buffers = &rx_buf, .count = 1};

    set_drdy(true);
    ret = spi_transceive(spi_dev, &spi_cfg, &tx, &rx);
    set_drdy(false);

    // Check for incoming telemetry packet and forward over BLE
    if (rx_buffer[0] == 0xA5 && rx_buffer[1] == 0x60) {
      uint8_t checksum = (rx_buffer[1] + rx_buffer[2] + rx_buffer[3]) & 0xFF;
      if (rx_buffer[4] != checksum) {
        LOG_WRN(
            "Telemetry checksum mismatch (got %02X, expected %02X) — forwarding anyway",
            rx_buffer[4],
            checksum);
      }

      if (current_conn == NULL) {
      } else {
        uint32_t now = k_uptime_get_32();
        bool in_backoff = (now < nus_send_backoff_until_ms);
        bool rate_ok = (now - last_nus_send_ms >= NUS_SEND_INTERVAL_MS);

        if (!in_backoff && rate_ok) {
          uint8_t nus_buf[11];
          uint16_t d0 = uwb_distances_mm[0];
          uint16_t d1 = uwb_distances_mm[1];
          uint16_t d2 = uwb_distances_mm[2];

          nus_buf[0] = rx_buffer[0];
          nus_buf[1] = rx_buffer[1];
          nus_buf[2] = rx_buffer[2];
          nus_buf[3] = rx_buffer[3];
          nus_buf[4] = (uint8_t)(d0 >> 8);
          nus_buf[5] = (uint8_t)(d0 & 0xFF);
          nus_buf[6] = (uint8_t)(d1 >> 8);
          nus_buf[7] = (uint8_t)(d1 & 0xFF);
          nus_buf[8] = (uint8_t)(d2 >> 8);
          nus_buf[9] = (uint8_t)(d2 & 0xFF);
          nus_buf[10] = (rx_buffer[1] + rx_buffer[2] + rx_buffer[3] +
                         nus_buf[4] + nus_buf[5] + nus_buf[6] +
                         nus_buf[7] + nus_buf[8] + nus_buf[9]) & 0xFF;

          int err = bt_nus_send(current_conn, nus_buf, 11);
          if (err == 0) {
            last_nus_send_ms = now;
            nus_send_backoff_until_ms = 0;
          } else {
            /* -22 EINVAL: notifications not enabled; -128 ENOTCONN: link down.
             * Back off to avoid hammering the stack and contributing to drops. */
            nus_send_backoff_until_ms = now + NUS_SEND_BACKOFF_MS;
            LOG_WRN("bt_nus_send failed: %d (backing off %d ms)",
                err,
                (int)NUS_SEND_BACKOFF_MS);
          }
        }
      }
    }

    if (ret < 0) {
      LOG_WRN("spi_transceive failed: %d", ret);
    }
  }
  return 0;
}

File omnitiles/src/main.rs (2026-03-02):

// SPDX-License-Identifier: MIT
// © 2025–2026 Christopher Liu

#![no_main]
#![no_std]

use cortex_m::delay::Delay;
use cortex_m_rt::entry;
use panic_halt as _;

use core::cell::RefCell;
use core::fmt::Write;

use hal::{
    pac,
    prelude::*,
    serial::{Config, Serial},
    spi::{Mode, Phase, Polarity, Spi},
};
use stm32f7xx_hal as hal;

use omnitiles::{
    control::{LinearController, LinearMode, Pid},
    drivers::{ActuonixLinear, Drv8873},
    hw::{pins_f767zi::BoardPins, Adc, ChipSelect, Led, SpiBus, Usart},
    protocol::{Command, Parser},
};

/// Map protocol speed byte (0–255) to motor set_speed magnitude in [0.0, 1.0].
fn speed_to_float(speed: u8) -> f32 {
    (speed as f32) / 255.0
}

#[entry]
fn main() -> ! {
    let dp = pac::Peripherals::take().unwrap();
    let cp = cortex_m::Peripherals::take().unwrap();

    let rcc = dp.RCC.constrain();
    let clocks = rcc.cfgr.freeze();
    let mut apb2 = rcc.apb2;

    let mut delay = Delay::new(cp.SYST, clocks.sysclk().raw());

    let pins = BoardPins::new(dp.GPIOA, dp.GPIOB, dp.GPIOC, dp.GPIOD);

    // LEDs are active-high on the F767ZI devboard but active-low on PCB v1
    let mut led_blue = Led::active_high(pins.leds.blue);
    let mut led_green = Led::active_high(pins.leds.green);
    let mut led_red = Led::active_high(pins.leds.red);

    let serial = Serial::new(
        dp.USART3,
        (pins.usart3.tx, pins.usart3.rx),
        &clocks,
        Config {
            baud_rate: 115_200.bps(),
            ..Default::default()
        },
    );
    let mut usart = Usart::new(serial);

    usart.println("Booting OmniTiles firmware...");

    let mut spi_bus = {
        let spi_mode = Mode {
            polarity: Polarity::IdleLow,
            phase: Phase::CaptureOnFirstTransition,
        };
        let spi1_raw = Spi::new(dp.SPI1, (pins.spi1.sck, pins.spi1.miso, pins.spi1.mosi));
        let spi1_enabled = spi1_raw.enable::<u8>(spi_mode, 100.kHz(), &clocks, &mut apb2);
        SpiBus::new(spi1_enabled)
    };
    let mut cs = ChipSelect::active_low(pins.spi1.cs);
    let drdy = pins.spi1.drdy;

    cs.deselect();

    let adc1 = RefCell::new(Adc::adc1(dp.ADC1));

    let pwm = dp.TIM3.pwm::<_, _, 1_000_000>(
        (pins.m1.in1, pins.m1.in2, pins.m2.in1, pins.m2.in2),
        50.micros(), // 20 kHz
        &clocks,
    );
    let (m1_in1, m1_in2, m2_in1, m2_in2) = pwm.split();

    let mut m1_actuator = ActuonixLinear::new(
        Drv8873::new(ChipSelect::active_low(pins.m1.cs)),
        m1_in1,
        m1_in2,
        pins.m1.nsleep,
        pins.m1.disable,
        Adc::make_reader(&adc1, 9), // ADC1_IN9
        150.0,                      // P16 has 150 mm stroke length
        20.0,                       // 20 mm buffer at bottom (retracted)
        35.0,                       // 35 mm buffer at top (extended)
    );
    m1_actuator.enable_outputs();
    let mut m1 = LinearController::new(
        m1_actuator,
        Pid::new(0.5, 0.01, 0.05),
        20.0,  // min_position_mm (buffer at retracted end)
        115.0, // max_position_mm (stroke 150 mm - buffer 35 mm at extended end)
        2.0,   // on_target_tolerance_mm
    );
    let mut m2_actuator = ActuonixLinear::new(
        Drv8873::new(ChipSelect::active_low(pins.m2.cs)),
        m2_in1,
        m2_in2,
        pins.m2.nsleep,
        pins.m2.disable,
        Adc::make_reader(&adc1, 12), // ADC1_IN12
        100.0,                       // T16 has 100 mm stroke length
        25.0,                        // 25 mm buffer at bottom (retracted)
        15.0,                        // 15 mm buffer at top (extended)
    );
    m2_actuator.enable_outputs();
    let mut m2 = LinearController::new(
        m2_actuator,
        Pid::new(0.5, 0.01, 0.05),
        25.0, // min_position_mm (buffer at retracted end)
        85.0, // max_position_mm (stroke 100 mm - buffer 15 mm at extended end)
        2.0,  // on_target_tolerance_mm
    );

    let mut parser = Parser::new();

    loop {
        const DT: f32 = 0.02;
        m1.step(DT);
        m2.step(DT);
        if m1.actuator.is_limit_braking() || m2.actuator.is_limit_braking() {
            led_red.on();
        } else {
            led_red.off();
        }

        if drdy.is_high() {
            delay.delay_ms(2_u32);

            let mut buf = [0u8; 128];

            let p16_raw = m1.actuator.position_raw();
            let t16_raw = m2.actuator.position_raw();

            // Scale 12-bit ADC (0-4095) down to 8-bit (0-255)
            let p16_pos = (p16_raw >> 4) as u8;
            let t16_pos = (t16_raw >> 4) as u8;

            buf[0] = omnitiles::protocol::messages::START_BYTE;
            buf[1] = omnitiles::protocol::messages::MSG_TELEMETRY;
            buf[2] = p16_pos;
            buf[3] = t16_pos;
            buf[4] = buf[1].wrapping_add(buf[2]).wrapping_add(buf[3]);

            cs.select();
            delay.delay_us(50_u32);
            spi_bus.transfer_in_place(&mut buf).unwrap_or_default();
            delay.delay_us(50_u32);
            cs.deselect();
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

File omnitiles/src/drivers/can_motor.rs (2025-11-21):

//! Motor control over CAN for SteadyWin GIM6010-48 with a GDZ468 driver.
//!
//! This module wraps the driver's custom CAN protocol for a single motor.

use crate::hw::CanBus;

use bxcan::{Frame, Id, OverrunError, StandardId};
use core::convert::TryInto;
use core::f32::consts::PI;
use micromath::F32Ext;

/// Error type for `CanMotor` operations.
#[derive(Debug)]
pub enum Error {
    /// Payload too long for a single CAN data frame (max 8 bytes total).
    PayloadTooLong,
    /// TX mailbox or transmit failure.
    TxMailbox,
    /// Receive-side CAN error.
    Rx(OverrunError),
    /// Response frame contained no data bytes.
    NoData,
    /// Response had a different command code than expected.
    UnexpectedCommand(u8),
}

impl From<OverrunError> for Error {
    fn from(e: OverrunError) -> Self {
        Error::Rx(e)
    }
}

/// High-level CAN motor for a single driver instance, parameterized by logical device address.
///
/// `DEV_ADDR` is the protocol device address (`Dev_addr`), in the range 1 to 254 inclusive. The
/// default `DEV_ADDR` is 0x01.
///
/// The driver will:
///   - transmit commands with `StdID = 0x100 | DEV_ADDR`
///   - expect responses from `StdID = DEV_ADDR`
pub struct CanMotor<const DEV_ADDR: u16>;

impl<const DEV_ADDR: u16> CanMotor<DEV_ADDR> {
    /// Create a new handle for this motor address.
    ///
    /// This is a zero-sized type; all state lives on the driver itself.
    #[inline]
    pub fn new() -> Self {
        Self
    }

    /// Host -> motor StdID (11-bit) used for commands.
    #[inline]
    fn host_id() -> StandardId {
        StandardId::new((0x100 | (DEV_ADDR & 0x7FF)) as u16).unwrap()
    }

    /// Motor -> host StdID (11-bit) used for responses.
    #[inline]
    fn dev_id() -> StandardId {
        StandardId::new(DEV_ADDR & 0x7FF).unwrap()
    }

    /// Send a command an optionally wait for its response.
    ///
    /// - `cmd` is the command code (e.g., 0xA2 for read speed).
    /// - `payload` is any extra bytes following the command code.
    /// - If `wait_reply` is true, this will block until a matching response frame (same device ID
    ///   and command code) is received.
    ///
    /// Returns:
    ///   - `Ok(Some(data))` when `wait_reply` is true and a response was received.
    ///   - `Ok(None)` when `wait_reply` is false.
    fn request_response<I>(
        &mut self,
        bus: &mut CanBus<I>,
        cmd: u8,
        payload: &[u8],
        wait_reply: bool,
    ) -> Result<Option<[u8; 8]>, Error>
    where
        stm32f7xx_hal::can::Can<I>: bxcan::Instance,
    {
        // Total payload including command must be <= 8 bytes
        if payload.len() > 7 {
            return Err(Error::PayloadTooLong);
        }

        // Build TX buffer
        let mut buf = [0u8; 8];
        buf[0] = cmd;
        let dlc = 1 + payload.len();
        buf[1..dlc].copy_from_slice(payload);

        // Transmit
        let tx_id = Self::host_id();
        let tx_result = bus
            .transmit_data(tx_id, &buf[..dlc])
            .ok_or(Error::PayloadTooLong)?;

        match tx_result {
            Ok(_status) => {}
            Err(_) => return Err(Error::TxMailbox),
        }

        if !wait_reply {
            return Ok(None);
        }

        // Wait for matching response
        loop {
            let frame: Frame = bus.receive()?;

            // Standard frame only
            let id = match frame.id() {
                Id::Standard(id) => id,
                Id::Extended(_) => continue,
            };

            // Only accept DEV_ADDR responses
            if id != Self::dev_id() {
                continue;
            }

            let data = match frame.data() {
                Some(d) if d.len() > 0 => d,
                _ => return Err(Error::NoData),
            };

            let resp_cmd = data[0];
            if resp_cmd != cmd {
                continue; // Ignore if different command
            }

            let mut out = [0u8; 8];
            let len = data.len().min(8);
            out[..len].copy_from_slice(&data[..len]);
            return Ok(Some(out));
        }
    }

    /// Clear any latched faults.
    pub fn clear_faults<I>(&mut self, bus: &mut CanBus<I>) -> Result<(), Error>
    where
        stm32f7xx_hal::can::Can<I>: bxcan::Instance,
    {
        let _ = self.request_response(bus, 0xAF, &[], true)?;
        Ok(())
    }

    /// Turn off motor output. The motor enters a free state and becomes uncontrollable (this is the
    /// state the motor enters after power-on).
    pub fn disable_output<I>(&mut self, bus: &mut CanBus<I>) -> Result<(), Error>
    where
        stm32f7xx_hal::can::Can<I>: bxcan::Instance,
    {
        let _ = self.request_response(bus, 0xCF, &[], false)?;
        Ok(())
    }

    /// Command the motor in speed control mode with a setpoint in rpm.
    ///
    /// - `rpm` is signed (negative values indicate reverse direction).
    /// - Resolution is 0.01 rpm
    pub fn set_speed_rpm<I>(&mut self, bus: &mut CanBus<I>, rpm: f32) -> Result<(), Error>
    where
        stm32f7xx_hal::can::Can<I>: bxcan::Instance,
    {
        // Convert to protocol units: little-endian signed 32-bit int, 0.01 rpm
        let scaled: i32 = (rpm * 100.0).round() as i32;
        let bytes = scaled.to_le_bytes();

        let _ = self.request_response(bus, 0xC1, &bytes, false)?;
        Ok(())
    }

    /// Read back the real-time motor speed in rpm.
    pub fn read_speed_rpm<I>(&mut self, bus: &mut CanBus<I>) -> Result<f32, Error>
    where
        stm32f7xx_hal::can::Can<I>: bxcan::Instance,
    {
        let resp = self
            .request_response(bus, 0xA2, &[], true)?
            .ok_or(Error::NoData)?;

        if resp[0] != 0xA2 {
            return Err(Error::UnexpectedCommand(resp[0]));
        }

        let speed_bytes: [u8; 4] = resp[1..5].try_into().expect("slice with exact length");
        let raw = i32::from_le_bytes(speed_bytes);
        let rpm = raw as f32 / 100.0;
        Ok(rpm)
    }

    // Read the raw status frame.
    pub fn read_status_frame<I>(&mut self, bus: &mut CanBus<I>) -> Result<[u8; 8], Error>
    where
        stm32f7xx_hal::can::Can<I>: bxcan::Instance,
    {
        let resp = self
            .request_response(bus, 0xAE, &[], true)?
            .ok_or(Error::NoData)?;

        if resp[0] != 0xAE {
            return Err(Error::UnexpectedCommand(resp[0]));
        }

        Ok(resp)
    }
}
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

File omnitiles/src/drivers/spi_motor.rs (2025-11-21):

//! Motor abstraction for DRV8873 SPI driver with a TIM2 quadrature encoder.
//!
//! This module includes functions to drive the motor and read encoder values.

use crate::drivers::drv8873::{Diag, Drv8873, Fault};
use crate::hw::{Encoder, SpiBus};

use micromath::F32Ext;

use stm32f7xx_hal::{
    gpio::{self, Output, PushPull},
    pac, spi,
};

/// Logical drive direction / mode for the H-bridge.
#[derive(Copy, Clone, Debug)]
pub enum Direction {
    Forward,
    Reverse,
    Brake,
    Coast,
}

/// Motor abstraction that combines a DRV8873 driver, four control pins, and a TIM2 encoder.
pub struct SpiMotor<
    const CS_P: char,
    const CS_N: u8,
    const IN1_P: char,
    const IN1_N: u8,
    const IN2_P: char,
    const IN2_N: u8,
    const SLP_P: char,
    const SLP_N: u8,
    const DIS_P: char,
    const DIS_N: u8,
> {
    drv: Drv8873<CS_P, CS_N>,
    enc: Encoder<pac::TIM2>,
    in1: gpio::Pin<IN1_P, IN1_N, Output<PushPull>>,
    in2: gpio::Pin<IN2_P, IN2_N, Output<PushPull>>,
    nsleep: gpio::Pin<SLP_P, SLP_N, Output<PushPull>>,
    disable: gpio::Pin<DIS_P, DIS_N, Output<PushPull>>,
    counts_per_rev: u32,
}

impl<
        const CS_P: char,
        const CS_N: u8,
        const IN1_P: char,
        const IN1_N: u8,
        const IN2_P: char,
        const IN2_N: u8,
        const SLP_P: char,
        const SLP_N: u8,
        const DIS_P: char,
        const DIS_N: u8,
    > SpiMotor<CS_P, CS_N, IN1_P, IN1_N, IN2_P, IN2_N, SLP_P, SLP_N, DIS_P, DIS_N>
{
    /// Construct a new `SpiMotor`.
    ///
    /// `counts_per_rev` is the encoder resolution at the mechanical shaft (after any gear ratio).
    pub fn new<In1Mode, In2Mode, SlpMode, DisMode>(
        drv: Drv8873<CS_P, CS_N>,
        enc: Encoder<pac::TIM2>,
        in1: gpio::Pin<IN1_P, IN1_N, In1Mode>,
        in2: gpio::Pin<IN2_P, IN2_N, In2Mode>,
        nsleep: gpio::Pin<SLP_P, SLP_N, SlpMode>,
        disable: gpio::Pin<DIS_P, DIS_N, DisMode>,
        counts_per_rev: u32,
    ) -> Self {
        let mut in1 = in1.into_push_pull_output();
        let mut in2 = in2.into_push_pull_output();
        let mut nsleep = nsleep.into_push_pull_output();
        let mut disable = disable.into_push_pull_output();

        in1.set_low();
        in2.set_low();

        // Initialize as awake + disabled
        nsleep.set_high();
        disable.set_high();

        Self {
            drv,
            enc,
            in1,
            in2,
            nsleep,
            disable,
            counts_per_rev,
        }
    }

    /// Tear down this motor and return its constituent parts.
    pub fn free(
        self,
    ) -> (
        Drv8873<CS_P, CS_N>,
        Encoder<pac::TIM2>,
        gpio::Pin<IN1_P, IN1_N, Output<PushPull>>,
        gpio::Pin<IN2_P, IN2_N, Output<PushPull>>,
        gpio::Pin<SLP_P, SLP_N, Output<PushPull>>,
        gpio::Pin<DIS_P, DIS_N, Output<PushPull>>,
    ) {
        (
            self.drv,
            self.enc,
            self.in1,
            self.in2,
            self.nsleep,
            self.disable,
        )
    }

    /// Initialize and set base configuration for the DRV8873.
    pub fn init<I, PINS>(&mut self, spi_bus: &mut SpiBus<I, PINS>) -> Result<(), spi::Error>
    where
        I: spi::Instance,
        PINS: spi::Pins<I>,
    {
        let _fault = self.drv.read_fault(spi_bus)?;
        let _diag = self.drv.read_diag(spi_bus)?;

        Ok(())
    }

    /// Read the FAULT status register.
    #[inline]
    pub fn read_fault<I, PINS>(
        &mut self,
        spi_bus: &mut SpiBus<I, PINS>,
    ) -> Result<Fault, spi::Error>
    where
        I: spi::Instance,
        PINS: spi::Pins<I>,
    {
        self.drv.read_fault(spi_bus)
    }

    /// Read the DIAG status register.
    #[inline]
    pub fn read_diag<I, PINS>(&mut self, spi_bus: &mut SpiBus<I, PINS>) -> Result<Diag, spi::Error>
    where
        I: spi::Instance,
        PINS: spi::Pins<I>,
    {
        self.drv.read_diag(spi_bus)
    }

    /// Access the underlying DRV8873 driver for advanced SPI control.
    #[inline]
    pub fn drv(&mut self) -> &mut Drv8873<CS_P, CS_N> {
        &mut self.drv
    }

    /// Put the driver into sleep mode.
    ///
    /// This shuts down most of the internal circuitry to reduce power consumption.
    #[inline]
    pub fn sleep(&mut self) {
        self.nsleep.set_low();
    }

    /// Wake the driver from sleep mode.
    #[inline]
    pub fn wake(&mut self) {
        self.nsleep.set_high();
    }

    /// Enable the motor and wake the driver if in sleep.
    #[inline]
    pub fn enable_outputs(&mut self) {
        self.wake();
        self.disable.set_low();
    }

    /// Disable the motor and coast.
    #[inline]
    pub fn disable_outputs(&mut self) {
        self.set_direction_pins(Direction::Coast);
        self.disable.set_high();
    }

    /// Configure IN1/IN2 pins for a given direction/mode.
    fn set_direction_pins(&mut self, dir: Direction) {
        match dir {
            Direction::Forward => {
                self.in1.set_high();
                self.in2.set_low();
            }
            Direction::Reverse => {
                self.in1.set_low();
                self.in2.set_high();
            }
            Direction::Brake => {
                self.in1.set_high();
                self.in2.set_high();
            }
            Direction::Coast => {
                self.in1.set_low();
                self.in2.set_low();
            }
        }
    }

    /// Drive the motor forward.
    #[inline]
    pub fn forward(&mut self) {
        self.set_direction_pins(Direction::Forward);
    }

    /// Drive the motor in reverse.
    #[inline]
    pub fn reverse(&mut self) {
        self.set_direction_pins(Direction::Reverse);
    }

    /// Apply brakes.
    #[inline]
    pub fn brake(&mut self) {
        self.set_direction_pins(Direction::Brake);
    }

    /// Coast (this sets outputs to HiZ).
    #[inline]
    pub fn coast(&mut self) {
        self.set_direction_pins(Direction::Coast);
    }

    /// Raw encoder position in ticks (signed).
    #[inline]
    pub fn position_ticks(&self) -> i32 {
        self.enc.position()
    }

    /// Encoder position converted to revolutions.
    #[inline]
    pub fn position_revs(&self) -> f32 {
        self.enc.position() as f32 / self.counts_per_rev as f32
    }

    /// Reset the encoder position to zero.
    #[inline]
    pub fn zero(&mut self) {
        self.enc.reset();
    }

    /// Convert a number of revolutions into encoder ticks.
    #[inline]
    pub fn ticks_for_revs(&self, revs: f32) -> i32 {
        (revs * self.counts_per_rev as f32).round() as i32
    }

    /// Compute a target tick position for a relative move from the current position.
    #[inline]
    pub fn target_for_delta_ticks(&self, delta_ticks: i32) -> i32 {
        self.position_ticks().wrapping_add(delta_ticks)
    }
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

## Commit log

2025-10-15 Use all LEDs
2025-10-16 Button go whrrrr
2025-10-17 SPI loopback test
2025-10-17 powerSTEP01 GetStatus
2025-10-21 Reset device
2025-11-06 Timer stuff
2025-11-09 LED hw abstraction
2025-11-10 Fix LED abstraction
2025-11-13 OmniTiles Schematic
2025-11-17 Docs and fix bug
    [main.rs]
2025-11-17 Add quadrature encoders
2025-11-18 DRV8873 driver
2025-11-18 First pass spi motor
2025-11-20 CAN motor first pass
2025-11-21 I think finish the drv8873 driver
2025-11-21 Lift motor abstraction with height
2025-11-21 PID control
2025-11-22 Use SPI1 for devboard and fix spi transfer
    [pins_f767zi.rs, spi.rs]
2025-11-22 Print SPI rx as hex
2025-11-22 Better testing printing
2025-12-01 Fix CAN filter stuff
    [can.rs, main.rs]
2025-12-01 Red LED is not drivable for F777
2025-12-02 Revert "Red LED is not drivable for F777"
    This reverts commit bb12feebca3835b31fcd62bf936f3664c680c09f.
    [pins.rs]
2025-12-02 Add motor 1 pins
2025-12-02 Add spi motor driver to motor re-exports
2025-12-02 SPI motor test
2025-12-03 Encoder comment
2025-12-03 Generate closure for reading a specific channel from ADC
2025-12-03 ADC pins
2025-12-03 Update SPI mode for SPI motor driver
2025-12-03 SPI motor is approx. 2803 counts per rev
2025-12-03 Motor cycling test + print revs, iprop, nfault
2026-01-24 Add pin definitions for new devboard
2026-01-24 Add P16 driver
2026-01-27 Remove old pin assignments
2026-01-27 Update old PCB pin structs to match new devboard
2026-01-27 Add P16 model to debug gui
    [p16_base.stl, p16_shaft.stl]
2026-01-27 Make generic actuonix linear driver
2026-01-27 Update GUI for two actuators
2026-01-27 Add T16 model
    [t16_base.stl, t16_carriage.stl]
2026-02-04 Add track actuator carriage offset
2026-02-04 Update pins for pwm control on PCBv1
2026-02-04 Remove unused gpioh import from PCBv1 pins
2026-02-04 Remove PWM for now in main
2026-02-15 SPI slave initialization
2026-02-15 BLE SPI integration
2026-02-19 Add f767zi pin definitions
2026-02-19 Set up base firmware for board
2026-02-19 Basic SPI
2026-02-20 Add ping button to gui
2026-02-20 Update pins for pwm
2026-02-20 Add back some pwm stuff
2026-02-20 Print command being run
2026-02-24 Telemetry 1 Hz
2026-02-24 Update ADCs for motor pots
2026-02-24 Fix bugs from new payload structure
    [main.py, main.rs]
2026-02-24 Add analog adc pins
2026-02-24 Add filtering for adc
2026-02-24 Updates at 10 Hz
2026-02-24 Back to 1 Hz
2026-02-24 Send brake on disconnect
2026-02-26 Use red LED if using auto brake
2026-02-26 Update GUI with mirrored actuators
2026-02-26 Brake on queue overflow
2026-03-01 Add pid control for actuonix actuators
